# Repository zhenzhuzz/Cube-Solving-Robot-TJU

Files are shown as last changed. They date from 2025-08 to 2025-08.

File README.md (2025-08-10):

# Cube-Solving-Robot-TJU

## 项目概述
`Cube-Solving-Robot-TJU` 是一个自动化魔方机器人，能够通过颜色识别和魔方还原算法，快速高效地还原打乱的魔方。该项目结合了图像识别、计算机算法、机械控制系统与硬件设计，目标是在比赛中完成魔方的自动还原，提升机器人的速度与精度。

该项目的魔方机器人采用了双臂和二指设计，符合比赛的具体要求，旨在通过精确的颜色识别、快速高效的魔方解法和精密的机械结构来实现比人类更快速和准确的魔方还原。

## Demo
Cube-Solving-Robot-TJU Demo

## 图片展示

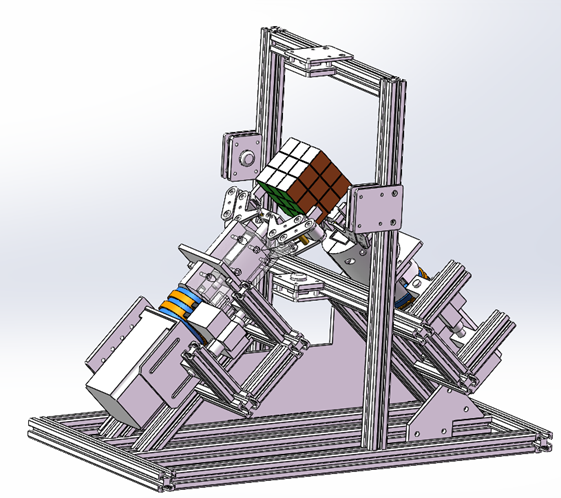
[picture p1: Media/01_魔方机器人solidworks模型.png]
魔方机器人solidworks模型
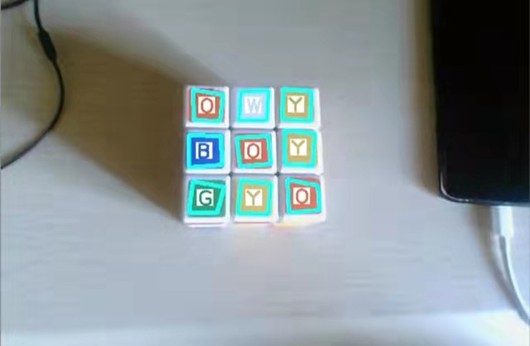
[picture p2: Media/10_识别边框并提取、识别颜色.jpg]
识别边框并提取、识别颜色
|  <br> *SolidWorks模型* |  <br> *识别边框并提取、识别颜色* |
| --- | --- |
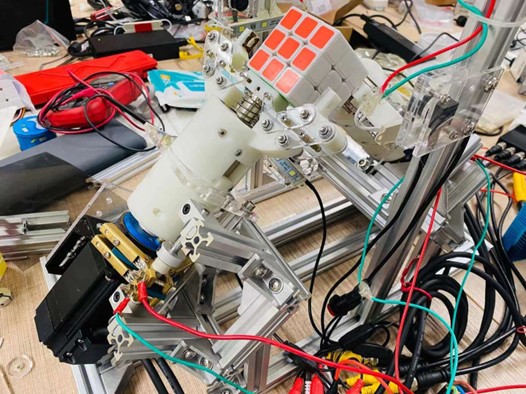
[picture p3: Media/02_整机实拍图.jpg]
整机实拍图
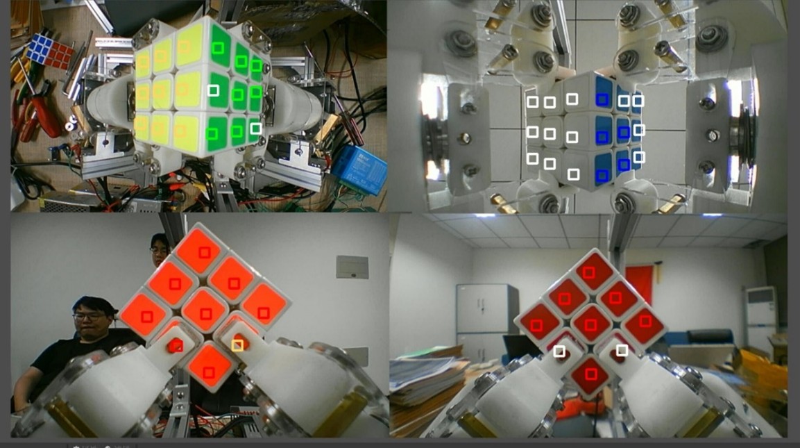
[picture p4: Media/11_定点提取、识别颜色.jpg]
定点提取、识别颜色
|  <br> *整机实拍图* |  <br> *定点提取、识别颜色* |

## 主要不足与改进建议
1. 建议放弃电磁铁驱动——虽响应快，但调试复杂、夹持力不足易掉落、电感大断电后反向电流易损坏继电器或 MOSFET，且长时间通电易烧毁线圈；相比之下，气缸虽速度慢，但力大且更可靠。  
2. 主体框架过度依赖角码螺栓和亚克力板，悬臂结构多、刚度不足，在手爪碰撞或夹持力作用下易产生位移。建议改用三角撑加固，并结合全槽铝型材与焊接或铆接方式，确保一次定位后不再松动。  
3. 赛前大幅结构调整风险高——比赛当日的微调易破坏此前的标定（如颜色识别的定点坐标）。应在光学与算法调试前，先完成并锁定机械结构。  
4. 手爪螺栓连接过多，运转振动中易松动。建议优化手爪结构或采用成品气动爪，减少维护工作量。  

## 比赛要求
根据比赛规则，本项目的魔方机器人满足以下要求：
- **双臂设计**：机器人使用双臂系统来操作魔方。
- **手指形式**：手指设计为二指形式，符合比赛的限制。
- **手腕转动与摆动**：手腕部分允许转动和摆动，以便完成魔方的操作。
- **固定手臂**：手臂本身是固定的，不会移动。
- **外形尺寸限制**：机器人的外廓尺寸不超过 480mm * 480mm * 480mm。
- **重量限制**：总重量不超过 20kg。
- **摄像头**：摄像头数量不限，机器人可自行增设光源。
- **魔方**：竞赛使用标准三阶魔方，决赛用魔方由组委会统一提供。

## 项目功能
- **颜色识别**：通过多个摄像头实时捕捉魔方的颜色块信息，并通过卷积神经网络（CNN）和机器学习算法实现高精度的颜色分类。
- **魔方还原算法**：使用二阶段算法（Kociemba's Algorithm）来解魔方，保证了在短时间内得到一个不超过20步的最优解。
- **控制系统**：使用Arduino控制系统，通过PWM调速步进电机和电磁铁控制机械臂与手爪精确执行魔方还原动作。

## 核心部件
### 1. 颜色识别系统
- **摄像头**：使用四个720P广角摄像头对魔方进行实时拍摄，每个摄像头负责不同角度的色块采集。
- **图像处理**：为了确保颜色识别的准确性，图像会经过腐蚀操作，以去除反光和噪点。使用基于CNN的深度学习模型进行颜色分类，确保高精度的识别，尤其在不同光照条件下。

### 2. 魔方还原算法
- **Kociemba算法**：该算法通过将魔方还原过程分为两个阶段，首先寻找一个阶段一的解，再通过阶段二的搜索得到完整的解。Kociemba的算法可以在几毫秒内生成一个最优解，平均不超过20步。
- **错误校验机制**：为了防止颜色识别误差导致的失败，系统会对魔方状态进行校验，确保颜色数据的准确性。若识别结果不符合标准，系统会自动重新识别。

### 3. 控制系统
- **Arduino控制板**：作为机器人“大脑”，接收并解析从计算机传输的还原步骤指令，控制步进电机、继电器、电磁铁等执行部件。
- **步进电机和电磁铁**：通过步进电机精确控制机械臂的旋转角度，电磁铁则负责操控机械手爪的开合。电磁铁的反应时间控制在15ms以内，确保动作迅速。

### 4. 执行系统
- **机械臂**：机械臂由3D打印技术制作，采用推拉式电磁铁驱动，提供高效、稳定的夹取动作。
- **手爪**：手爪采用电磁铁控制，具有极高的精度和反应速度，能够迅速夹取或松开魔方。

## 项目结构
```bash
Cube-Solving-Robot-TJU/
├── docs/          # 项目文档
│   ├── overview.md         # 系统概述
│   ├── hardware.md         # 硬件结构
│   ├── algorithm.md        # 算法设计
│   └── results.md          # 测试与结果
├── src/           # 代码源文件
│   ├── color_recognition/  # 颜色识别相关算法
│   │   ├── color_detection.py
│   │   └── cnn_model.py    # CNN模型代码
│   ├── cube_solver/        # 魔方还原算法
│   │   ├── kociemba.py     # Kociemba算法实现
│   │   └── solver.py       # 其他还原算法
│   ├── control_system/     # 控制系统及执行系统
│   │   ├── arduino_control.py
│   │   ├── motor_control.py
│   │   └── electromagnet.py # 电磁铁控制
│   └── utils/              # 工具函数
│       └── image_processing.py
├── hardware/      # 硬件设计文件
│   ├── pcb_design/           # PCB设计文件
│   ├── schematics/           # 电路原理图文件
│   └── 3d_models/            # 3D打印模型
├── data/          # 数据文件，包括训练数据、日志等
│   ├── training_data/        # CNN训练数据
│   └── logs/                 # 运行日志
├── README.md      # 项目说明文件
└── LICENSE        # 项目许可证
```

安装与运行
-----

1. **安装依赖**：  
    该项目使用Python编写，依赖以下库：
    
    ```bash
    pip install -r requirements.txt
    ```
    
2. **运行颜色识别**：  
    运行颜色识别模块来进行魔方色块的提取与分类：
    
    ```bash
    python src/color_recognition/color_detection.py
    ```
    
3. **解魔方**：  
    使用Kociemba算法解决魔方，计算最优解：
    
    ```bash
    python src/cube_solver/solver.py
    ```
    
4. **控制执行系统**：  
    启动Arduino控制系统，并通过串口接收指令执行动作：
    
    ```bash
    python src/control_system/arduino_control.py
    ```

数据
--

### 颜色识别数据

为了训练CNN模型，我们使用了多个光照条件下的魔方色块图像数据集。该数据集经过标注，包含不同角度、不同光照条件下的RGB数据。数据集主要用于训练颜色分类模型，提高在真实环境中的识别精度。

### 算法结果

使用Kociemba算法解魔方时，项目会输出每一步的旋转指令，控制机械臂和电磁铁执行相关动作。经过测试，魔方还原时间平均为20秒，且还原正确率超过90%。

项目优势
----

1. **高精度颜色识别**：采用CNN和集成学习算法，确保了在不同光照环境下的高识别准确率。
    
2. **快速魔方解法**：通过Kociemba算法，能够在极短的时间内求解魔方的最优解，减少了机器人的运动时间。
    
3. **稳定高效的控制系统**：Arduino控制系统配合步进电机和电磁铁驱动，确保了机械臂和手爪的稳定性和精确性。
    
4. **可扩展性强**：模块化设计，使得系统易于维护和扩展，可以根据需要进行硬件或算法的升级。

许可证
---

本项目采用 MIT License 许可协议。

致谢
--

感谢所有开源工具和库对本项目的支持，尤其是`OpenCV`、`TensorFlow`、`Kociemba`库以及`Arduino`社区的贡献。

```

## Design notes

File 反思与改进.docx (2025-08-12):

1、建议不要使用电磁铁。电磁铁虽然理论上比气缸响应速度快，但调试起来非常麻烦。这次比赛我们魔方2组采用了电磁铁，主要有三个缺点：

一是力不够，能买到的电磁铁最大的保持力为65N，但还是会在魔方转动的过程中因为夹持力不够而掉落，远不如气缸的力大。

二是电磁铁内部的电感很大，因此在断电时仍会有很大的电流存在，电流从电磁铁流出，从继电器的输出端流入，有可能会击穿继电器。在整个调试过程中，我们烧坏了2个继电器（虽然继电器是机械结构控制通断，但还是有可能击穿），以及很多个MOS管（继电器都能击穿，更不用说MOS管了）。

三是不能长时间通电，使得调试过程很麻烦。电磁铁主体是线圈，长时间（不超过30s）通电会烧坏，因此调试时得时刻记着给电磁铁断电，比较麻烦。

再结合比赛时其他高校的情况来看，绝大多数都是使用气缸，因为更稳定而且容易控制。由于我们学校的魔方机器人经验还不足，因此应该先把重心放在制作出能稳定还原魔方的机器上，不用刻意追求速度。

2、制作的主体框架不稳定。我们2组主体框架用的是铝型材和亚克力板，连接用的是角码和螺栓，还有多处是悬臂梁，结构不稳定。因此在手爪故障，发生碰撞时会使支撑结构发生位移，从而严重影响手爪的对中性。因此以后设计支座应该多利用三角形结构，并且多开槽开销孔，将底座完全固定，这样在调整好对中后，就不会再受手爪碰撞的影响。

3、切忌赛前大调结构。我们组的机器人在比赛前一晚还能正常运行，但在比赛当天早上因为手爪夹不紧，所以不断调整手臂的位置，使得原本固定好的颜色识别的点发生了移动，因此在比赛时没能识别魔方的颜色，这种行为应该极力避免。因为我们颜色识别采用的是定点识别，因此调试好设备后，手爪的位置就不能动了，这样才能保证打的点都落在魔方正确的色块上。

4、机械结构一定要尽早搭出来，后期调灯光和颜色识别还需要一定时间。机械结构一定要以稳为主，支座一定要固定好，这样在后期调试的时候才能确定下环境。魔方机器人最重要的就是保证环境不变，因此整个结构要有很好的抵抗外界变化的性能，无论是魔方滑落发生碰撞，还是环境灯光发生变化，都不能影响手臂结构和魔方的识别。

5、我们组的手爪采用了太多螺栓连接，在转动时是螺栓在转动，因此调试几次后手爪上的螺栓就会松了，使得调试过程非常麻烦，需要反复拧紧，建议下次改良一下手爪结构，或者直接买气动手爪来使用。

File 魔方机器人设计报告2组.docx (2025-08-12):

指导教师：宋晓威 于树强 参赛队员：朱 镇 段金宇 李姝影

魔方机器人设计报告

天津大学代表队

# 一、系统概述

## 1.1 项目背景

中国高校智能机器人创意大赛是一项有广泛影响的全国性的学科竞赛。2017年首届中国高校智能机器人创意大赛由中国高等教育学会、教育部工程图学课程教学指导委员会、中国高校智能机器人创意大赛组委会共同主办，浙江大学机器人研究院、中国高等教育学会工程教育专业委员会承办，决赛由浙江省余姚市人民政府承办。之后该大赛每年举办一次，至今已经连续举办3届，大赛以“更好、更快、更强”为主题，既培养学生提问题的能力，也培养学生解决问题的能力，高校参与该竞赛的积极高、参与面广，本竞赛已列入中国高等教育学会发布的《2020年全国普通高校学科竞赛排行榜》。

为进一步推进高校学生创新意识和创造能力培养，激励广大学生踊跃参加课外科技实践，有效推动新工科人才培养，经中国高校智能机器人创意大赛组委会研究，决定启动第四届中国高校智能机器人创意大赛工作。

第四届中国高校智能机器人创意大赛设三个主题和一个邀请赛，鼓励学生根据自己的专业特长和兴趣爱好选择其一参赛。其中，主题二（创意竞技）为“魔方机器人——挑战更快”：参照人类魔方竞速规则，设计制作魔方机器人，综合运用机械、电子、信息和自然科学知识，实现比人“计算”更快、“翻动”更加灵活迅速的目标。

## 1.2 需求分析

在研读历届魔方机器人决赛程序和裁判规则的基础上，我们发现，比赛对还原魔方的速度、准确性，机械结构的稳定性均提出了一定的要求，经过分析，我们认为魔方机器人至少需要具备以下功能：

## 1.2.1颜色识别

魔方机器人需要在一定的光照条件下（可加人工光源），识别魔方各色块的颜色，从而获得RGB信息。颜色识别需要对每个方块的颜色精确把握。近年来ｏｐｅｎｃｖ的发展使得此项成为现实。

### 1.2.2 魔方还原算法

获取魔方各面的颜色数据（包括颜色信息和位置／顺序信息）后，魔方机器人通过算法将数据转化为特定形式作为输入量求解还原步骤，还需要一个辅助程序优化理论还原步骤，进一步简化得到实际还原步骤，然后输出可执行步骤给执行系统，从而还原魔方，这要求还原魔方算法的简洁高效；

## 1.2.3控制算法及电路系统

得到还原魔方算法输出数据后，需要一套控制算法及相应配套的电路系统将还原步骤传递给执行系统，而控制系统不宜复杂，应保证稳定高效，能快速响应。

## 1.2.4执行机构

执行机构应满足精度要求，保证手爪对中性以及和魔方的匹配程度，确保在还原魔方的过程中，将误差控制在容错范围内，尽量避免误差积累带来的影响。在控制系统的控制下，执行机构需要稳定且准确地完成给定动作，为防止魔方在还原过程中受力移位、脱落，执行系统及主要机械结构对相关构型及材料具有一定的受拉、受压等强度要求。

## 1.3 项目预期

在参考往届众多优秀作品的基础上，我们将针对性地对视觉识别算法及机械结构进行大幅改进，预计可使颜色识别更加准确快速，机械爪结构更加稳定，制作及装配精度更高，识别准确率预期在95%以上，还原魔方速度预计在20s内，总时长预计在25s内，还原正确率预计在90%以上。

# 二、作品简介

## 2.1 总体构成

本组的魔方机器人总体使用了Arduino 1块，电磁铁2个，PCB板1块，MOS管2个，220V/AC-24V/DC开关电源1个，220V/AC-12V/DC开关电源1个，720P摄像头4个，采集卡1块。电机及支架和驱动器2组，电滑环及碳刷2组，6mm光轴2根，锁紧环4个，光轴支承座4个，3D打印件手爪2个，LED小灯4条、铝型材、轴承、螺母、连接件、角码、导线等若干。

## 2.2 机械结构

二轴魔方机器人结构示意图如图2.1所示，图中，魔方机器人的外部框架均为铝型材。

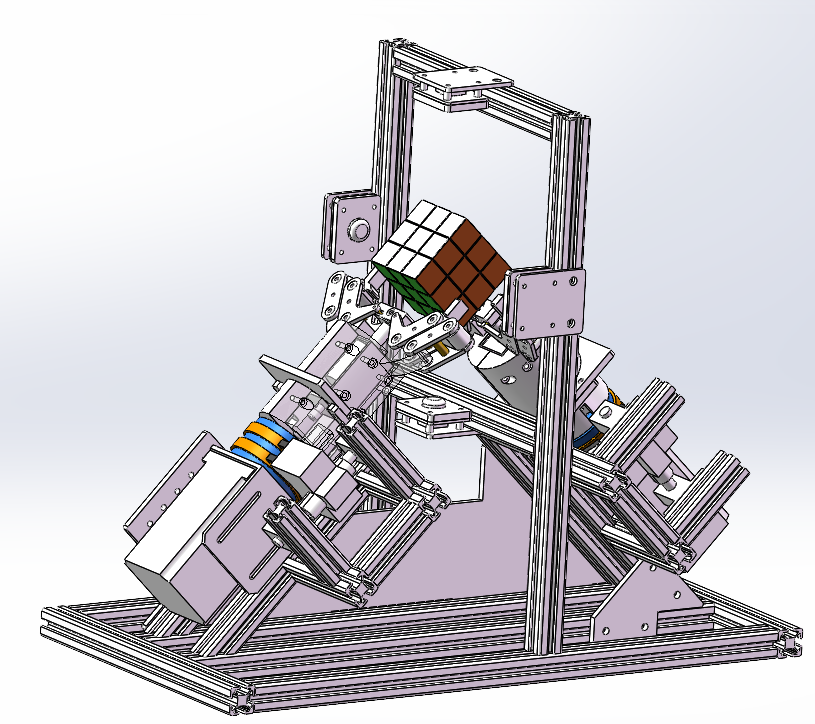
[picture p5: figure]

图2.1 魔方机器人solidworks模型

魔方机器人以中间门形框架所在的平面为基准面左右对称，两侧的三角支架上装有闭环步进电机，通过联轴器与机械臂相连。联轴器外固定有电滑环，配合电刷，解决电磁铁的绕线问题。手指通过手指连接件与机械臂相连，其夹放动作通过机械臂内部的推拉式电磁铁进行控制。闭环步进电机、机械臂、滑环的回转轴都位于同一轴线上，且与另一侧轴线呈90°夹角，魔方也位于该角处。机器人的图像采集通过固定在门型框架上的四个摄像头实现。

在功能分工上，机器人整体按照可分为动力系统、控制系统和执行系统。两臂的两个步进电机由驱动板供电，控制手臂的旋转；通过电磁铁控制手爪的开合。使用Arduino通过串口接收计算机发来的还原步骤，经过处理加工计算后得到魔方还原的指令，将计算机的每个指令翻译为一组信号输出。通过Arduino，实现对电机驱动板和电磁铁的控制，利用PCB简化连线，利用MOS管代替继电器。气泵控制手爪开合，电机驱动板驱动电机控制手臂旋转，两者配合完成一次完整的拧转动作。

## 2.3 算法设计

在算法设计上，本组魔方机器人的主算法由图像识别位置校准程序、图像识别程序、图像分割显示程序、图像信息转换程序、还原算法、坐标转换程序和控制程序七个子程序组成。

图2.2 程序框图

# 三、硬件结构

## 3.1 输入元件

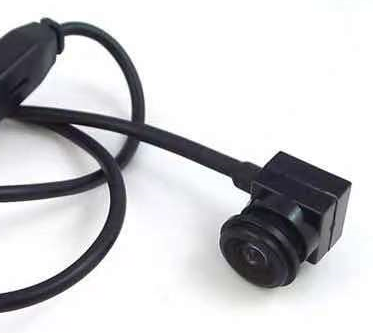
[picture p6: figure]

图3.1 摄像头实物图

本魔方机器人使用4个平头广角720P摄像头作为色彩信息输入元件。

## 3.2 控制系统

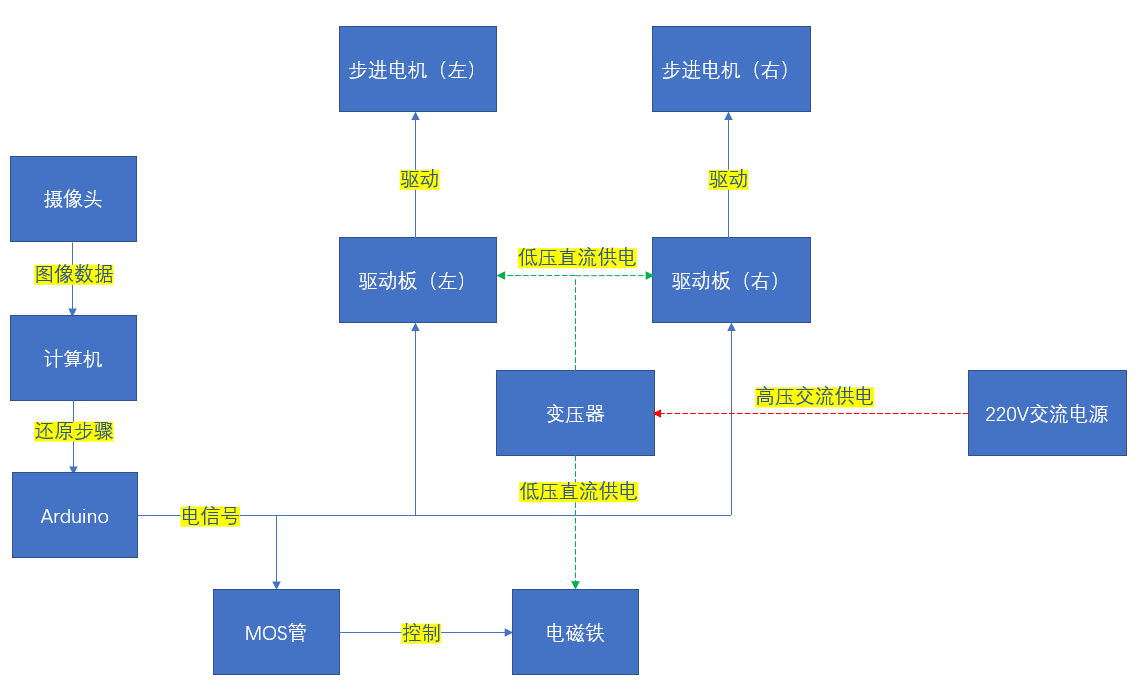
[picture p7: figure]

图3.2 控制系统框图

采用计算机作为本魔方机器人的“大脑”，处理摄像头输入的数据，并求解还原魔方的步骤，输出给Arduino；使用Arduino作为机器人的“脊髓”，通过串口接收计算机发来的还原步骤，经过处理加工计算后得到魔方还原的指令，并将计算机的每个指令翻译为一组信号输出，实现对电机驱动板的控制，控制手臂旋转，通过MOS管控制电磁铁，以此控制手爪开合，两者配合完成一次完整的拧转动作。

MOS管采用A0D4184型号，击穿电压电流分别为40V、50A，自带光耦隔离，控制信号和被控设备电源隔离，大大提高刚干扰，可兼容Arduino控制板，高电平启动，低电平停止，PWM调速。

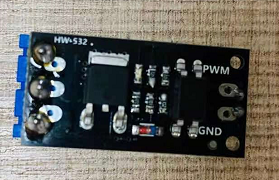
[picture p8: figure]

图3.3 MOS管实物图

本组自行绘制一版PCB，提前将铜线布好，将MOS管，Arduino，24V，地线以及电机使能、步进、旋转方向集成在板子上，方便接线，机器的封装性更好

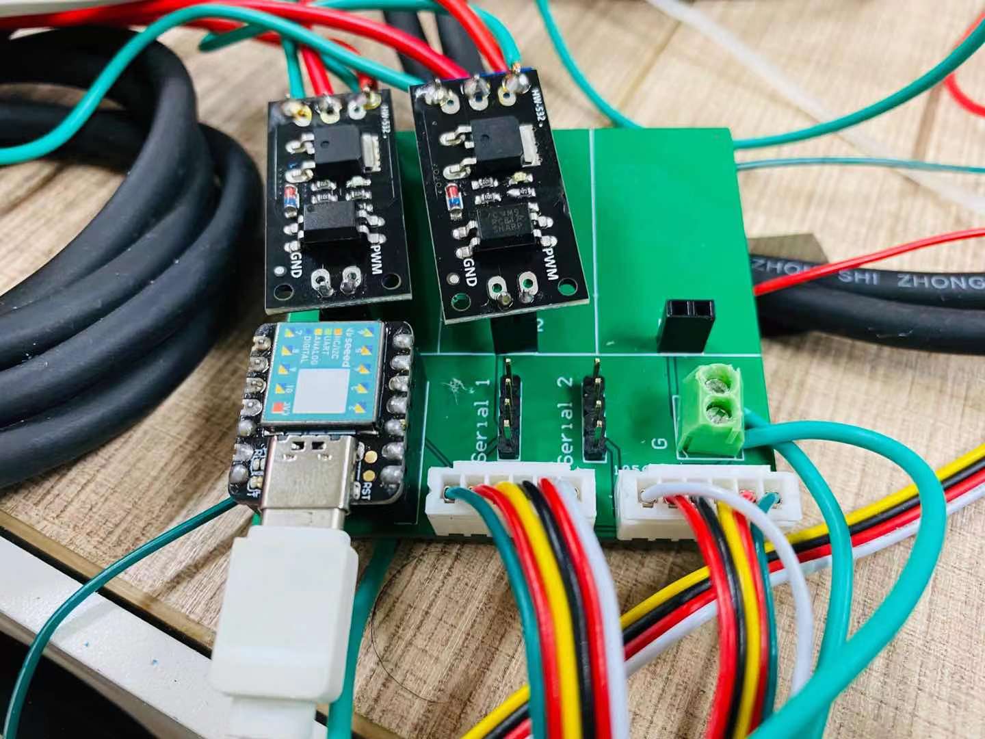
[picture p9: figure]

图3.4 MOS管和Arduino集成在PCB上的实物图

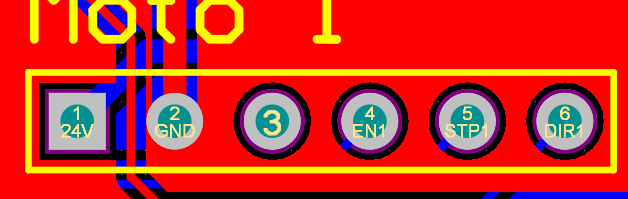
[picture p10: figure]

图3.5 PCB端子绘制图

## 3.3 执行系统

## 3.3.1 电磁铁

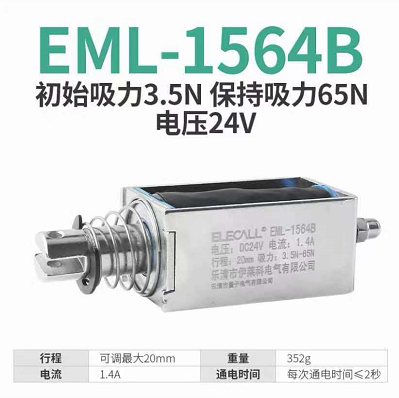
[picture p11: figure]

图3.6 电磁铁实物图

本组采用推拉式电磁铁，型号为伊莱科的EML-1564B，工作电压24V，工作电流2A，初始吸力3.5N，保持吸力65N，重量352g，最大可调行程20mm。通过电磁铁推动手爪结构，带动手指张开闭合，从而实现抓紧和松开两种状态。并且电磁铁响应迅速，与气缸相比执行速度更快，还原魔方的速度更快。

## 3.3.2 机械臂

机械臂内部结构如图3.7所示：

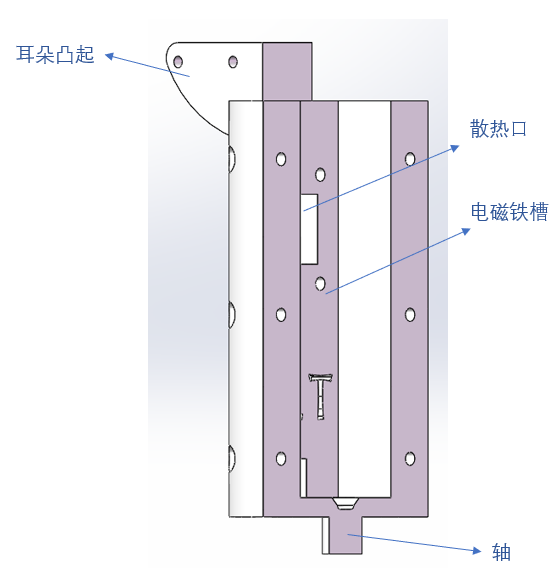
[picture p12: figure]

图3.7 机械臂内部结构

机械臂采用3D打印技术制作，内部有电磁铁槽，用来安装推拉式电磁铁。下端的圆柱状凸起为机械臂的轴，利用联轴器与电机轴固定。手指连接件与机械臂上端的耳状凸起相连，牵引手指的夹放动作。在一边的机械臂的轴上还设计有一个平键，用以保证机械臂和联轴器的连接，如图3.8所示。

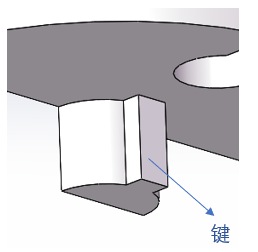
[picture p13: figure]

图3.8 轴上的键

## 3.3.3 机械手爪

本魔方机器人每一手臂末端有两个手指，均由3D打印材料制作，通过I型手指连接件和L型手指连接件分别与机械臂的耳状凸起及手掌连接。手掌与电磁铁的铁芯连接。机械手爪的结构图如图3.9所示：

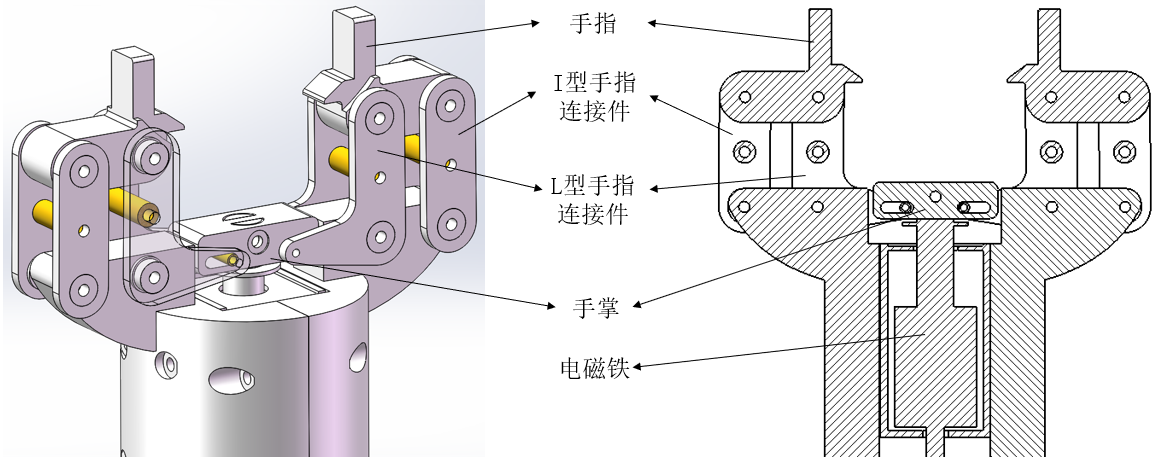
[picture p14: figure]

图3.9机械手爪结构示意图

当电磁铁通过电流时铁芯收缩，电流断开时通过弹簧弹出铁芯，从而带动手掌上下运动，推动L型手指连接件、I型手指连接件运动，实现手指夹放动作。

## 3.3.4 步进电机

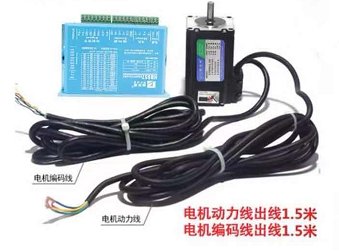
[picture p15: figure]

图3.10 步进电机实物图

电机采用57闭环步进电机，型号为57HSZ2N，输出力矩2.2N·m，机身长度99mm，轴径8mm，出轴方式为单出轴，电流为4A，转速1000rpm以上扭矩下降，最高2000rpm。

电机轴与联轴器相连，联轴器又与机械臂想连，从而带动机械臂转动。

## 3.3.5 电滑环

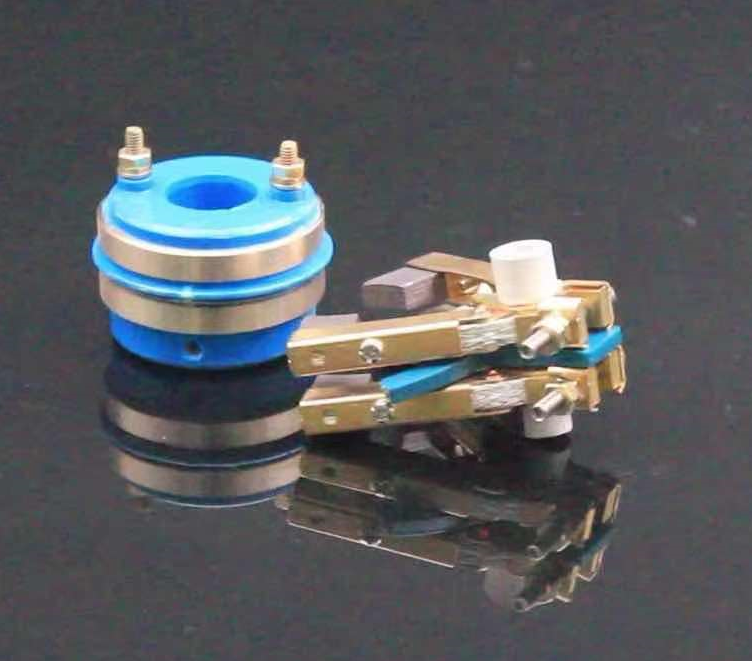
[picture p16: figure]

图3.11 电滑环和电刷实物图

电磁铁的导线通过电滑环和电刷来连接电源，使得电磁铁旋转时，导线不会缠绕起来。电滑环选用人字形刷架总成二组SR20*50*34-2。

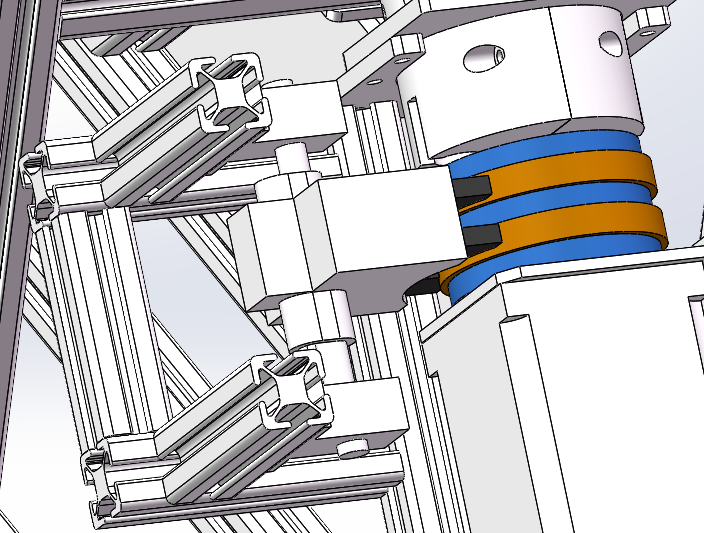
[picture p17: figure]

图3.12 电滑环和电刷的安装位置

## 3.4 动力系统

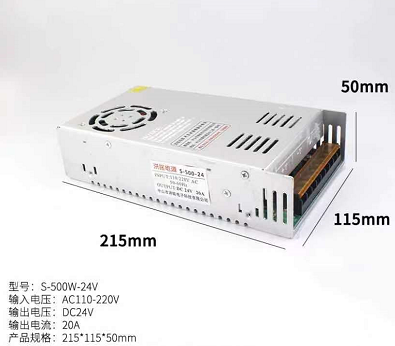
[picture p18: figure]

图3.11 变压器实物图

电源方面选择220V家用交流电转24V直流电，所用变压器为S-500W-24V变压器，长215mm，宽115mm，高50mm，输入电压范围为110V~220V/AC，输出电压为24V/DC，最大输出电流为20A，最大功率500W。

# 四、控制算法及软件实现

软件算法是魔方机器人核心，其大致可分为三个部分，颜色识别、解魔方、控制机构运动，其中颜色识别和解魔方我们使用Python语言使其运行在个人电脑上，控制机构部分我们使用Arduino来控制电机的转动，继电器的开闭等动作，以下将对各部分进行详述。

## 4.1 颜色识别

对于颜色识别的算法，我们首先需要进行对魔方上各个色块的颜色进行采集。我们想到的有两种方法：第一个是对魔方进行边框的识别，通过算法筛选出其9个色块，这样就可以知道我们所需要颜色的位置。这种方法虽然非常方便，但在实际的运用中效果并不是特别好。由于机械臂上会有各种的机构挡住魔方一定部分，使边缘识别的成功了大幅减小，非常不稳定，而在比赛中我们需要的是其能够稳定得运行。所以我们将这种方法运用到后面其他的地方。

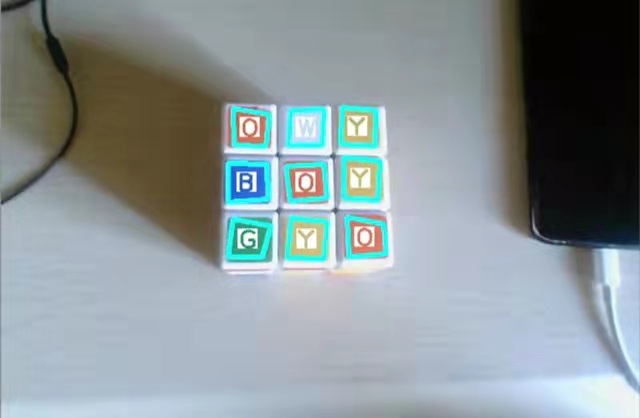
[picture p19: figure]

图4.1 识别边框并提取、识别颜色

由于魔方在机械臂上的位置是固定的，所以便可以取第二种方法，对摄像头图像的进行定点识别。这种方法的缺点是在前期进行调试时非常麻烦，需要设各点坐标，同时需要魔方和摄像头的位置不能有一丝轻微的移动，对于魔方放的位置也提出了很大的要求，但在经过前期调试后这种方法可以非常稳定运行，所以我们使用了第二种定点识别的方法。

### 4.1.1图象腐蚀

但是在取得我们想要的色块之后，由于反光或者是摄像机的噪点，使得用于识别的数据十分杂乱，于是我们就使用了图形学中的“图象腐蚀”操作对数据集以及进入识别的图象进行了处理。

如下图就是图象腐蚀算法处理的结果，可以看到结果很好。

图4.2 未经腐蚀的图象

图4.3 腐蚀结束的图象

如上图所示，经过腐蚀后的图象以及完全消去了反光带来的影响。符合我们对数据的要求。

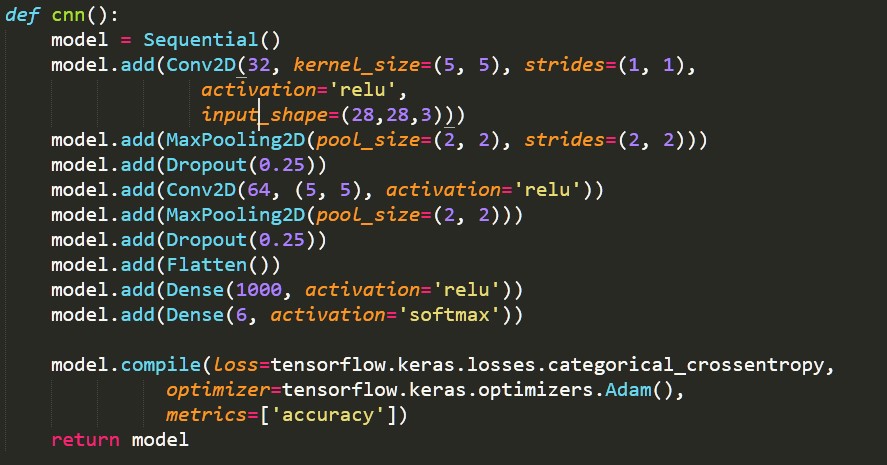
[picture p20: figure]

在取得我们所需要的颜色值后我们就需要通过算法来判断该颜色值是什么，首先我们尝试了对RGB数值设置阈值来判断，但这种方法需要人工来调阈值非常麻烦，同时其准确率非常低，不同环境下识别颜色的值相差非常大。所以我们又采用卷积神经网络CNN来进行颜色的识别，只需要采用第一种识别边框的方法通过摄像头采集还原好的魔方的六个面，来非常方便得获取颜色值，再来训练模型，在这种方法下训练的模型在测试训练集时可以达到基本100%的准确度。

图4.4 CNN的结构

但其在实际运用的时候却在上下摄像头的识别有非常大的失误，由于上下识别需要对两个对角面进行识别。所以我们对其训练集进行了补充，添加了许多不同光照条件下的颜色数据，这种方法后他的准确度大幅提升。但是为了以防万一，我们同时采用了集成学习的机器学习方法训练了另一套识别模式。如图就是我们采用的集成学习的结构。

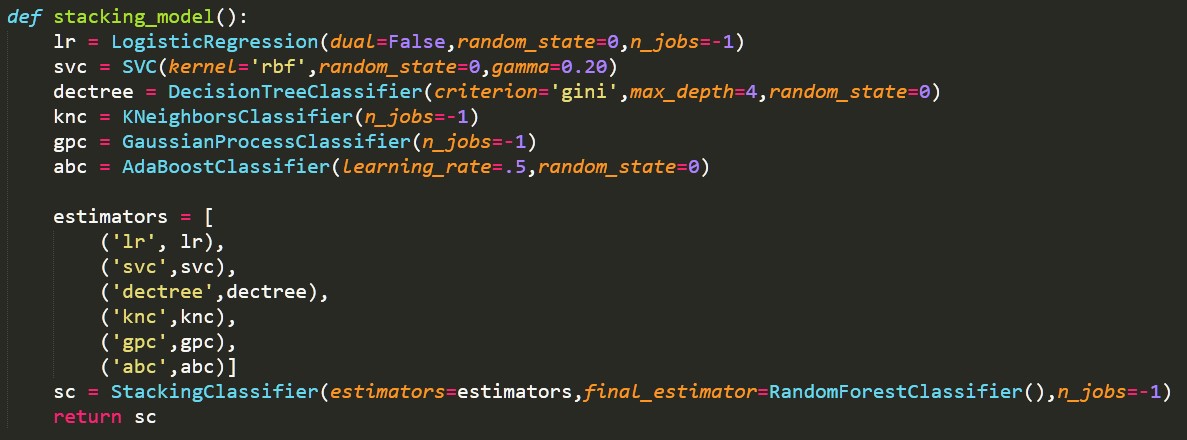
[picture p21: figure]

图4.5　集成学习模型

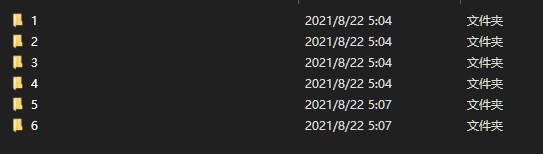
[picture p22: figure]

图4.6 通过机器学习所建立数据的数据库

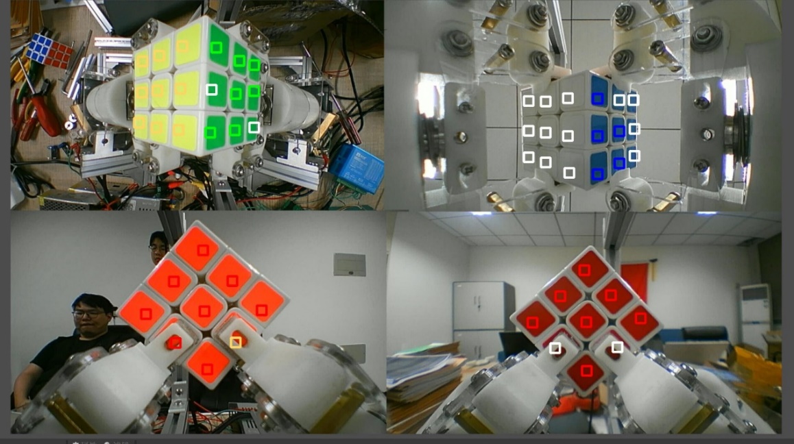
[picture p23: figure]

综上所述，通过首先通过识别边框的方法来获取非常方便快速得获取不同光照下的颜色的RGB值，通过这些大量的数据来进行模型的训练，再通过定点识别的方法来获取实际运行过程中魔方的颜色值，通过调用模型来进行颜色的判断。

图4.7 定点提取、识别颜色

## 4.2 解魔方

解魔方我们采用了当前最主流的计算机解魔方算法，二阶段算法（Two phase algorithm，又称Kociemba's algorithm），在当前计算机上，对于一个充分打乱的魔方，该算法平均可以在几毫秒的时间内得到一个不超过20步的解法。魔方可能的状态数实在太多了，达到4.3*10^19，这是一个很大数量级，而二阶段算法顾名思义，就是把还原的过程分成了两个阶段。首先进行阶段一的搜索，得到了阶段一的最优解。接着通过阶段二的搜索，得到了阶段二解法，从而产生了一个步的完整解法。通过不断搜索解法再进行比较，获得其最快解。由于这个算法过于高深，所以我解魔方为调用Kociemba库来完成。虽然我们已经极力提高颜色的准确率了但是若光照改变，其所识别的颜色还是会有几率错误，某个色块的颜色会在两种颜色中跳动，而将错误的颜色信息输入Kociemba库，整个程序将会报错，从而导致运行失败，所以我们设计了检验程序，将颜色分别标为1，2，3，4，5，6，将所有面的颜色相加，若其不等于21*9，那么便说明识别中有错误，需要重新进行识别。然后这一步遇到的最大的困难是对四个摄像头依次识别数据的处理，使其成为其库的标准输入，即每个面都有一个字符表示，U为上表面，D为下表面，L为左表面，R为右表面，F为前表面，B为后表面，解完的魔方每个面都是同一个颜色，所以UDLRFB可以代表每个面的颜色。假定我们让上表面U为白色，下表面D为黄色，左表面L为红色，右表面R为橙色，前表面F为蓝色，后B表面为绿色。当魔方打乱后，则下图表示的每个面的单元格颜色就可能是之前任何面的某一个颜色，这样便可以让魔方可任意摆放在手臂上。我们按照如下顺序将单元格颜色变成字符串：`U1`, `U2`, `U3`, `U4`, `U5`, `U6`, `U7`, `U8`, `U9`, `R1`, `R2`, `R3`, `R4`, `R5`, `R6`, `R7`, `R8`, `R9`, `F1`, `F2`, `F3`, `F4`, `F5`, `F6`, `F7`, `F8`, `F9`, `D1`, `D2`, `D3`, `D4`, `D5`, `D6`, `D7`, `D8`, `D9`, `L1`, `L2`, `L3`, `L4`, `L5`, `L6`, `L7`, `L8`, `L9`, `B1`, `B2`, `B3`, `B4`, `B5`, `B6`, `B7`, `B8`, `B9`。所以当我们输入字符串"UBL..."，表示U1为白色，U2为绿色，U3为红色，以此类推，即可定义所有面的单元格标志字符串。

以下便是各字符所在的位置：

|************|

|U1*U2*U3|

|************|

|U4*U5*U6|

|************|

|U7*U8*U9|

|************|

|***********|***********|***********|***********|

|L1*L2*L3|F1*F2*F3|R1*R2*R3|B1*B2*B3|

|***********|***********|***********|***********|

|L4*L5*L6|F4*F5*F6|R4*R5*R6|B4*B5*B6|

|***********|***********|***********|***********|

|L7*L8*L9|F7*F8*F9|R7*R8*R9|B7*B8*B9|

|***********|***********|***********|***********|

|************|

|D1*D2*D3|

|************|

|D4*D5*D6|

|************|

|D7*D8*D9|

|************|

再将其输出处理为我们需要数据。解魔方步骤字符串包含空格字符，含义如下：

- 单个字符表示所代表的面顺时针旋转90度。
- 单个字符带一撇，表示代表的面逆时针旋转90度。
- 单个字符带2，表示代表的面旋转180度。

比如R U R’ U R U2 R’ U, 表示右表面顺时针旋转90度，下表面顺时针旋转90度，右表面逆时针旋转90度，下表面顺时针旋转90度，右表面顺时针旋转90度，下表面旋转180度，右表面逆时针旋转90度，下表面顺时针旋转90度。Kociemba库输出的步骤只是六个面的转动，而由于我们的魔方是双臂四指来完成步骤，所以我们需要进行坐标系的转换，例如Kociemba库解出的算法为将U面进行顺时针旋转90度，而我们的机械结构需要现将魔方整个进行翻转，来让处于上面的U面转至下面，从而使手臂可以拧到这个面，而在这个过程中整个魔方的坐标系就会进行旋转，Kociemba库解出的后面的步骤就要进行改变。这样输出的步骤便是我们希望手臂所能进行的运动。我们便可将其传入Arduino。

## 4.3 魔方控制

最后便是电脑与Arduino之间的通信与Arduino控制机械的运动，将解出电脑来的通过调用serial库来通过串口通信来将步骤的字符串传给Arduino，Arduino每次读取两个字符那便是单个步骤，同时剩余的步骤将存在于数据缓存区，Arduino同时也会通过串口来将步骤完成的信息进行反馈，以此来达到计时的目的。在Arduino收到步骤信息后它便要输出不同PWM信号来控制电机的转速，逻辑信号控制电机的正反转，逻辑信号控制继电器的开关以此来控制电磁的开关从控制手臂的张合。对于两个逻辑型号非常简单，只需输出高低电平，需要注意的是继电器的连接端的选择使手臂在低电平的信号下为闭合状态，在输入高电平是张开状态。

而PWM信号则会复杂许多。步进电机（也称脉冲电机），将电脉冲转换为相应的角位移或线位移的电磁机械装置，具有快速启动，停能力，在电机的负荷不超过它能提供的动态转矩时，可以通过输入脉冲来控制它在一瞬间的启动或者停止。在非超载的情况下，步距角和转速只和输入的脉冲频率有关，和环境温度，气压，振动无关，也不受电网电压的波动和负载变化的影响，因此，控制较为精准，即给电机一个脉冲信号，电机则转过一个步距角。信号开始运行后，步进电机将从0度旋转目标度数，每次一个分度。而转速则为PWM信号的频率决定的，一个脉冲信号，便会转一个分度。在调试完后我们需要使电机转速提升，这就需要我们加快频率，而当频率到超过Arduino上限时我们便要调低分度值，这是便会发现电机由于转速太快会丢步。这就需要我们对电机的启动与停止来设置加速度，即使PWM信号的频率由低到目标值，再由目标值到0。这样电机的转速便会由一开始的慢变快，再由快变慢。从而使其的峰值转速达到非常高而不会丢步，而由于加速时间和减速时间其实非常短，所以总的转速时间会有非常大的提升。从而加快整个机构的速度。

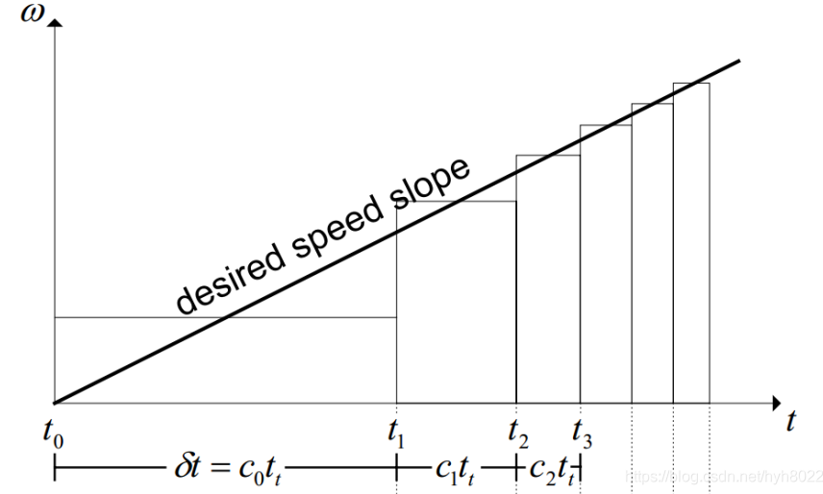
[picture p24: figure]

图4.8 步进电机加减速的实现

# 五、总结

## 5.1 优势

1、按系统功能分，机器人整体可分为动力系统、控制系统和执行系统。在执行逻辑上，首先4个摄像机得到指令后拍摄图片并发送至计算机。然后计算机处理图像并提取色块信息，通过算法解算出步骤后发送信号至下位机。最后下位机控制电机旋转与电磁阀的开闭，进而完成手腕拧转和手指夹取的基本动作。通过以上三个步骤还原打乱的魔方。

2、机械手爪的驱动控制。本作品的机械手爪夹、放动作的驱动装置为电磁铁，具有反应速度快、成本低、重量轻、体积小的优点。

3、机械手爪的机械结构。为配合电磁铁的驱动特性，本机械手爪结构极具创新特色。其两个手指均采用I型和L型手指连接件与机械手臂和手掌相连，通过电磁铁弹出、收进手掌来控制手指的夹、放动作。该结构性能稳定、反应迅速，在电磁铁的驱动下可高效完成手指的夹、放动作。

4、采用半遮光-多摄像头图像识别策略，提高识别精度，缩短识别时间。通过不完全透明的亚克力板提供较为柔和的光照，保证图像亮度；将包含图像信息的RGB空间数据，实现色调与饱和度、明度的分离，提升颜色识别的简便性和准确性；多摄像头的设置避免采样时手臂需多次旋转的问题，大大缩短图像识别时间识别。

5、使用Python开源算法库Kociemba，解算过程时间短效率高，解算结果步骤简单步数少。使用强大的功能函数kociemba.solve()，能够轻易在ms级的时间得到平均20步（5次测量的数据）包含还原步骤的字符串，再通过Python的字符串处理函数规范化字符串，得到能够被下位机识别的指令序列。

经过多次测试，该魔方机器人能高标准完成机器人大赛给出的任务，效果出色，性能稳定，还原速度快。

## 5.2 可以改进的方面

在调试的过程中，我们还发现了许多可以改进的方面：

1.机械结构材料及其精度。不同的零部件采用不同的材料，有各自的机械精度，在组装时又会有一定的精度差。故魔方机器人整体机械结构的精度对魔方复原的稳定性有一定影响，当转速过快时，会出现魔方滑落甚至甩出的现象。

针对此现象，小组尝试不同的3D打印材料，以提高机械臂和机械手爪的精度；不同机械零件连接时，加强固定力度；在手指内侧粘贴橡胶膜，增大手指与魔方之间的摩擦力。

2.光线强度变化。自然条件下，外界光线会随时间而发生变化。光线强弱影响了摄像头对魔方色块颜色的识别与提取，会使上位机获得错误信息。

针对此现象，小组采用补光设备，使魔方周围光线尽量保持不变，削弱自然光变化而产生的影响。

3.电磁铁的反应周期。小组采用的电磁铁控制电路已经将电磁铁铁芯收缩的时间控制在15 ms 以内，但铁芯的释放过程仍有较长时间，约为60 ms 。

针对此现象，小组采取给电磁铁增设弹簧的方法，加大铁芯释放所受到的回程力，缩短释放时间。

# 六、实物图

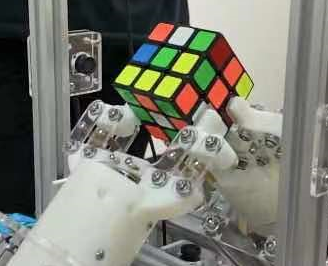
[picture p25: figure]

图6.1 手爪部分实拍图

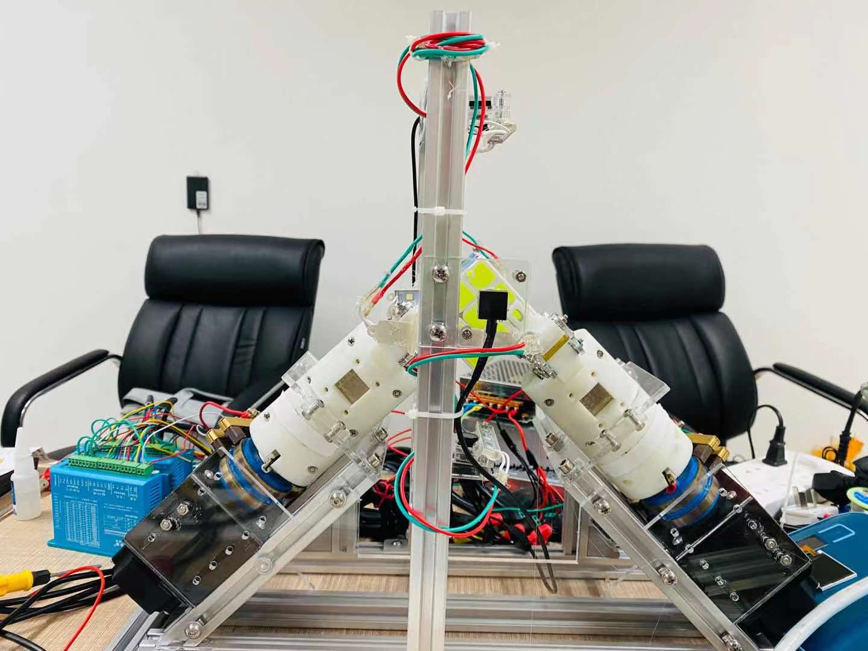
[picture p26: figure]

图6.2总体实拍图

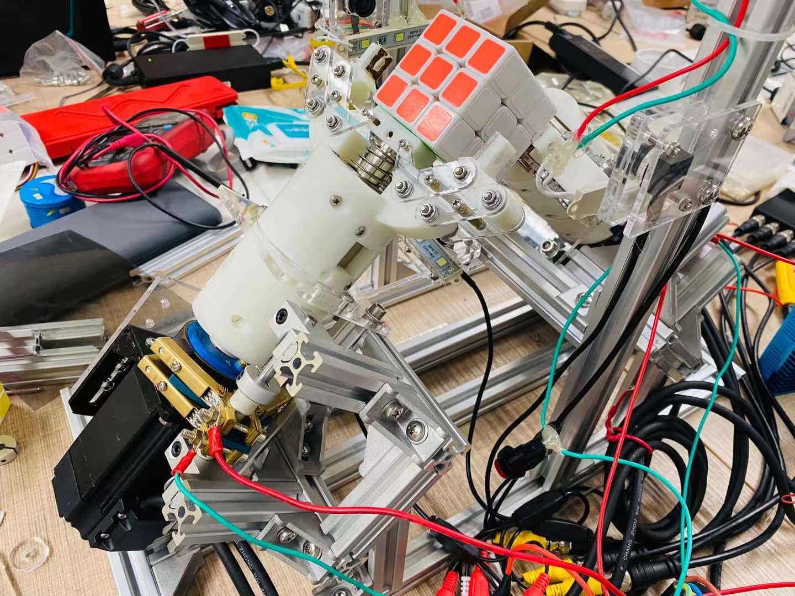
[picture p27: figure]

图6.3 侧视图

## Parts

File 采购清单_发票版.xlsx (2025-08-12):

序号 | 名称 | 规格 | 购买链接 | 单价 | 数量 | 价格（含税） |  | 采购人 | 有无发票 | 备注
1 | STM32F103C8T6开发板最小系统板 | 单片机核心板 | https://detail.tmall.com/item.htm?id=631557979854&spm=a1z09.2.0.0.50192e8df31Cot&_u=92jd7h41f013 | ¥40.98 | 1 | ¥40.98 | ¥40.98 | 朱镇 | 有 | 已焊接
2 | Arduino uno r3入门学习套件 | 标准创客版（含主板） | https://detail.tmall.com/item.htm?id=601125598796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 | ¥103.00 | 1 | ¥103.00 | ¥103.00 | 朱镇 | 有
3 | 45度角铝 | 2020-45度角铝（含紧固件） | https://detail.tmall.com/item.htm?id=576353788076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 | ¥7.56 | 5 | ¥37.80 | ¥243.30 | 朱镇 | 有
4 | 圆柱头内六角螺栓 | M6*16+垫片 | https://detail.tmall.com/item.htm?id=576376737278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 | ¥0.44 | 10 | ¥4.40 |  | 朱镇 | 有
5 | 圆柱头内六角螺栓 | M5*8+垫片 | https://detail.tmall.com/item.htm?id=576376737278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 | ¥0.35 | 20 | ¥7.00 |  | 朱镇 | 有
6 | 圆柱头内六角螺栓 | M5*10+垫片 | https://detail.tmall.com/item.htm?id=576376737278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 | ¥0.35 | 20 | ¥7.00 |  | 朱镇 | 有
7 | 角码 | 2020角码（含紧固件） | https://detail.tmall.com/item.htm?id=576621463575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 | ¥1.90 | 25 | ¥47.50 |  | 朱镇 | 有
 | 滑块螺母 | 欧标20M4 | https://detail.tmall.com/item.htm?id=576220220243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 (https://m.tb.cn/h.4zXMLN4?sm=ecf60e) | ¥0.72 | 10 | ¥7.20 |  | 朱镇 | 有
 | 滑块螺母 | 欧标20M5 | https://detail.tmall.com/item.htm?id=576220220243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 (https://m.tb.cn/h.4zXMLN4?sm=ecf60e) | ¥0.72 | 20 | ¥14.40 |  | 朱镇 | 有
 | 铝型材 |  | https://detail.m.tmall.com/item.htm?id=608414321666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 | ¥118.00 | 1 | ¥118.00 |  | 朱镇 | 有 | 详见铝型材清单
3 | Arduino 下载线 | 1.5m | https://detail.tmall.com/item.htm?id=643970809000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 | ¥7.95 | 1 | ¥7.95 | ¥7.95 | 朱镇 | 有
20 | LM2596S DC-DC直流可调稳压模块 | 5A大功率75W | https://detail.tmall.com/item.htm?id=581544496424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 (https://item.taobao.com/item.htm?id=567829133337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) | ¥15.23 | 1 | ¥15.23 | ¥15.23 | 朱镇 | 有
6 | 304垫圈 | M3*7*0.5 | https://detail.tmall.com/item.htm?id=15730068817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 | ¥1.50 | 1 | ¥1.50 | ¥12.17 | 朱镇 | 有 | 拍1件50颗
7 | 304垫圈 | M4*9*0.8 | https://detail.tmall.com/item.htm?id=15730068817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 | ¥1.50 | 1 | ¥1.50 |  | 朱镇 | 有 | 拍1件50颗
9 | 304十字盘头螺钉 | M3*20 | https://detail.tmall.com/item.htm?id=537903695538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 | ¥3.24 | 1 | ¥3.24 |  | 朱镇 | 有 | 拍1件50颗
8 | 304十字盘头螺钉 | M3*30 | https://detail.tmall.com/item.htm?id=537903695538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 | ¥4.03 | 1 | ¥4.03 |  | 朱镇 | 有 | 拍1件40颗
10 | 双通六角铜柱 | M3*15 | https://detail.tmall.com/item.htm?id=16626695446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 | ¥1.90 | 1 | ¥1.90 |  | 朱镇 | 有 | 拍1件10颗
5 | 继电器 | 1路5V（红板继电器） | https://detail.tmall.com/item.htm?id=41231430731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 (https://detail.tmall.com/item.htm?id=593291231082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) | ¥4.24 | 1 | ¥4.24 | ¥13.74 | 朱镇 | 有
5 | 继电器 | 2路5V（红板继电器） | https://detail.tmall.com/item.htm?id=41231430731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 (https://detail.tmall.com/item.htm?id=593291231082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) | ¥9.50 | 1 | ¥9.50 |  | 朱镇 | 有
4 | 伊莱科直流推拉式电磁铁EML系列 | EML-1253B（12V）吸力45N | https://detail.tmall.com/item.htm?id=571228541835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 | ¥49.00 | 1 | ¥49.00 | ¥49.00 | 朱镇 | 有
5 | 梅花联轴器 | 外径25 长度30 孔04至12 | https://detail.tmall.com/item.htm?id=593291231082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 | ¥16.00 | 1 | ¥16.00 | ¥16.00 | 朱镇 | 有 | 8转12，开4键槽
19 | USB摄像头 |  | https://item.taobao.com/item.htm?id=567829133337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 | ¥82.00 | 1 | ¥82.00 | ¥82.00 | 朱镇 | 有
 | 集电环+碳刷 | 人字形刷架总成二组 SR20*50*34-2 | https://detail.tmall.com/item.htm?id=613640927612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 | ¥101.16 | 2 | ¥202.31 | ¥202.31 | 朱镇 | 有 | 需定制，具体尺寸根据实际确定
20 | 法兰轴承 | 3*8*4无挡边 | https://item.taobao.com/item.htm?id=558845796019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 | ¥19.00 | 2 | ¥38.00 | ¥38.00 | 朱镇 | 有 | 拍1件10颗
 | 304六角螺母 | M3 | https://detail.tmall.com/item.htm?id=597726726154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 | ¥2.60 | 1 | ¥2.60 | ¥2.60 | 朱镇 | 有 | 拍1件100颗
 | 304十字盘头螺钉 | M3*10 | https://detail.tmall.com/item.htm?id=537903695538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 | ¥3.50 | 1 | ¥3.50 | ¥5.60 | 朱镇 | 有 | 拍1件80颗
10 | 双通六角铜柱 | M3*16 | https://detail.tmall.com/item.htm?id=16626695446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 | ¥2.10 | 1 | ¥2.10 |  | 朱镇 | 有 | 拍1件10颗
20 | 57闭环步进电机 | 扭矩2.2Nm，编码线1.5m | https://item.taobao.com/item.htm?id=533749071599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 | ¥263.24 | 1 | ¥263.24 | ¥267.00 | 朱镇 | 有
20 | 57闭环步进电机支架 | 带4个螺丝 | https://item.taobao.com/item.htm?id=19085543855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 (https://item.taobao.com/item.htm?id=533749071599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) | ¥3.76 | 1 | ¥3.76 |  | 朱镇 | 有
20 | 3D打印 | 树脂材料光固化 | https://detail.tmall.com/item.htm?id=628981891558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 | ¥118.00 | 1 | ¥118.00 | ¥118.00 | 朱镇 | 有
10 | 304十字盘头螺钉 | M3*25 | https://detail.tmall.com/item.htm?id=537903695538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 | ¥3.60 | 1 | ¥3.60 | ¥14.30 | 朱镇 | 有 | 拍1件40颗
8 | 304十字盘头螺钉 | M5*8+垫片 | https://detail.tmall.com/item.htm?id=537903695538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 | ¥2.30 | 3 | ¥6.90 |  | 朱镇 | 有 | 拍1件20颗
 | 304垫圈 | M5*10*1 | https://detail.tmall.com/item.htm?id=15730068817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 | ¥1.90 | 2 | ¥3.80 |  | 朱镇 | 有 | 拍1件50颗
20 | 开关电源 | 24V20A500W输出线套餐 | https://detail.tmall.com/item.htm?id=613635946038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 | ¥90.00 | 1 | ¥90.00 | ¥90.00 | 朱镇 | 有
20 | 法兰轴承 | 3*8*4有挡边 | https://item.taobao.com/item.htm?id=558845796019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 | ¥18.00 | 1 | ¥18.00 | ¥18.00 | 朱镇 | 有 | 拍1件10颗
 | 316内六角螺丝 | M3*14 | https://detail.tmall.com/item.htm?id=556840829042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 | ¥6.80 | 1 | ¥6.80 | ¥6.80 | 朱镇 | 有 | 拍1件50颗
4 | 伊莱科直流推拉式电磁铁EML系列 | EML-1253B（12V）吸力45N | https://detail.tmall.com/item.htm?id=571228541835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 | ¥52.00 | 1 | ¥52.00 | ¥52.00 | 朱镇 | 有
20 | 法兰轴承 | 3*8*4有挡边 | https://item.taobao.com/item.htm?id=558845796019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 | ¥18.00 | 3 | ¥54.00 | ¥54.00 | 朱镇 | 有 | 拍1件10颗
 | 304十字盘头螺钉 | M2*10 | https://detail.tmall.com/item.htm?id=537903695538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 | ¥3.24 | 1 | ¥3.24 | ¥3.24 | 朱镇 | 有 | 拍1件100颗
10 | 双通六角铜柱 | M2*16 | https://detail.tmall.com/item.htm?id=637681799522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 | ¥5.40 | 1 | ¥5.40 | ¥5.40 | 朱镇 | 有 | 拍1件30颗
20 | 光轴 | 硬轴6*100mm | https://item.taobao.com/item.htm?id=15106654058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 (https://detail.tmall.com/item.htm?id=628981891558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) | ¥2.00 | 2 | ¥4.00 | ¥59.00 | 朱镇 | 有
20 | 光轴支架 | SK6 内径6 | https://item.taobao.com/item.htm?id=16936800487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 | ¥7.00 | 4 | ¥28.00 |  | 朱镇 | 有
20 | 锁紧环 | SCS6 内径6外径20厚度8 | https://item.taobao.com/item.htm?id=593599133092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 | ¥4.00 | 4 | ¥16.00 |  | 朱镇 | 有
20 | 运费 |  |  | ¥11.00 | 1 | ¥11.00 |  | 朱镇 | 有
20 | 不锈钢弹簧 | 线径0.8mm | https://detail.tmall.com/item.htm?id=628266591747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 | ¥5.00 | 1 | ¥5.00 | ¥11.00 | 朱镇 | 有 | 一包10只
20 | 不锈钢弹簧 | 线径1mm | https://item.taobao.com/item.htm?id=15106654058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 (https://detail.tmall.com/item.htm?id=628981891558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) | ¥6.00 | 1 | ¥6.00 |  | 朱镇 | 有 | 1包10只
 | 304六角螺母 | M4 | https://m.tb.cn/h.fZuOHYF?sm=1deb6b | ¥2.20 | 1 | ¥2.20 | ¥21.97 | 朱镇 | 有 | 拍1件50颗
 | 304六角螺母 | M5 | https://m.tb.cn/h.f0rTZwA?sm=b804d9 | ¥2.97 | 1 | ¥2.97 |  | 朱镇 | 有 | 拍1件50颗
 | 316内六角螺钉 | M4*12 | https://m.tb.cn/h.f0rhV2p?sm=cfd9c5 | ¥3.56 | 2 | ¥7.12 |  | 朱镇 | 有 | 拍1件20颗
11 | 316内六角螺钉 | M5*10 | https://m.tb.cn/h.faCiYGY?sm=2407e0 | ¥4.68 | 1 | ¥4.68 |  | 朱镇 | 有 | 拍1件20颗
11 | 316内六角螺钉 | M5*12 | https://m.tb.cn/h.faCiYGY?sm=2407e0 | ¥5.00 | 1 | ¥5.00 |  | 朱镇 | 有 | 拍1件20颗
5 | 继电器 | 2路5V（红板继电器） | https://detail.tmall.com/item.htm?id=41231430731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 (https://detail.tmall.com/item.htm?id=593291231082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) | ¥9.50 | 1 | ¥9.50 | ¥9.50 | 朱镇 | 有
5 | 梅花联轴器 | 外径25 长度30 孔04至12 | https://detail.tmall.com/item.htm?id=593291231082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 | ¥16.00 | 1 | ¥16.00 | ¥16.00 | 朱镇 | 有 | 8转12，开4键槽
20 | LM2596S DC-DC直流可调稳压模块 | 5A大功率75W | https://detail.tmall.com/item.htm?id=581544496424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 (https://item.taobao.com/item.htm?id=567829133337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) | ¥15.23 | 1 | ¥15.23 | ¥15.23 | 朱镇 | 有
4 | 伊莱科直流推拉式电磁铁EML系列 | EML-1253B（12V）吸力45N | https://detail.tmall.com/item.htm?id=571228541835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 | ¥52.00 | 1 | ¥52.00 | ¥52.00 | 朱镇 | 有
20 | 57闭环步进电机 | 扭矩2.2Nm，编码线1.5m | https://item.taobao.com/item.htm?id=533749071599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 | ¥252.04 | 1 | ¥252.04 | ¥259.42 | 朱镇 | 有
20 | 57闭环步进电机支架 | 带4个螺丝 | https://item.taobao.com/item.htm?id=19085543855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 (https://item.taobao.com/item.htm?id=533749071599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) | ¥3.38 | 1 | ¥3.38 |  | 朱镇 | 有
4 | 运费 |  |  | ¥4.00 | 1 | ¥4.00 |  | 朱镇 | 有
20 | 3D打印 | 树脂材料光固化 | https://detail.tmall.com/item.htm?id=628981891558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 | ¥118.00 | 1 | ¥118.00 | ¥118.00 | 朱镇 | 有
20 | 塔簧 | 1*12*25*40*9 | https://m.tb.cn/h.fbn7K2Z?sm=a1d823 | ¥2.00 | 2 | ¥4.00 | ¥22.00 | 朱镇 | 有
20 | 塔簧 | 1*12*22*26*6 | https://m.tb.cn/h.fbn7K2Z?sm=a1d823 | ¥2.00 | 2 | ¥4.00 |  | 朱镇 | 有
20 | 塔簧 | 1*18*23*30*6 | https://m.tb.cn/h.fbn7K2Z?sm=a1d823 | ¥2.00 | 2 | ¥4.00 |  | 朱镇 | 有
20 | 运费 |  |  | ¥10.00 | 1 | ¥10.00 |  | 朱镇 | 有
16 | 滑块螺母 | 欧标20M4 | https://detail.tmall.com/item.htm?id=576220220243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 (https://m.tb.cn/h.4zXMLN4?sm=ecf60e) | ¥0.72 | 20 | ¥14.40 | ¥63.00 | 朱镇 | 有
17 | 滑块螺母 | 欧标20M5 | https://detail.tmall.com/item.htm?id=576220220243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 (https://m.tb.cn/h.4zXMLN4?sm=ecf60e) | ¥0.72 | 20 | ¥14.40 |  | 朱镇 | 有
17 | T型螺母 | 欧标20M5 | https://m.tb.cn/h.f0rPjI9?sm=e39ee0 | ¥0.58 | 20 | ¥11.60 |  | 朱镇 | 有
 | 运费 |  |  | ¥22.60 | 1 | ¥22.60 |  | 朱镇 | 有
20 | 硅胶条 | 长150mm 宽100mm 厚0.3 0.5 0.7 0.9mm | https://m.tb.cn/h.fZuv0F6?sm=3e91c3 | ¥120.00 | 1 | ¥120.00 | ¥120.00 | 朱镇 | 有 | 买错尺寸了，应该买长15mm宽10mm，留给下一届用
20 | 偏振片 | 15*15cm 0.17mm厚光面无胶 | https://m.tb.cn/h.fbnNVB4?sm=58ee10 | ¥39.90 | 1 | ¥39.90 | ¥39.90 | 朱镇 | 有
17 | T型螺母 | 欧标20M5 | https://m.tb.cn/h.f0rPjI9?sm=e39ee0 | ¥0.58 | 20 | ¥11.60 | ¥65.17 | 朱镇 | 有
15 | 角码 | 2020角码（含紧固件） | https://detail.tmall.com/item.htm?id=576621463575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 | ¥1.90 | 20 | ¥38.00 |  | 朱镇 | 有
 | 运费 |  |  | ¥15.57 | 1 | ¥15.57 |  | 朱镇 | 有
7 | 304垫圈 | M4*12*1 | https://m.tb.cn/h.faC95mI?sm=b88fbd | ¥6.49 | 1 | ¥6.49 | ¥10.48 | 朱镇 | 有 | 拍1件50颗
7 | 304垫圈 | M5*12*1 | https://m.tb.cn/h.faC95mI?sm=b88fbd | ¥3.99 | 1 | ¥3.99 |  | 朱镇 | 有 | 拍1件50颗
20 | 导线 | 0.3平方红色100米 | https://m.tb.cn/h.f1P3JEc?sm=d2d195 | ¥32.00 | 1 | ¥32.00 | ¥32.00 | 朱镇 | 有
4 | 伊莱科直流推拉式电磁铁EML系列 | EML-1564B（24V）吸力65N | https://m.tb.cn/h.fYnO0FI?sm=4fb968 | ¥55.00 | 2 | ¥110.00 | ¥133.00 | 朱镇 | 有
 | 运费 |  |  | ¥23.00 | 1 | ¥23.00 |  | 朱镇 | 有
 | 电源线 | 三脚带端子 | https://m.tb.cn/h.fciky9T?sm=b525a8 | ¥13.00 | 1 | ¥13.00 | ¥31.00 | 朱镇 | 有 | 拍1件200颗
20 | 开关电源 | 12V2A25W | https://m.tb.cn/h.fYyTEib?sm=e93f20 | ¥18.00 | 1 | ¥18.00 |  | 朱镇 | 有 | 拍1件100颗
9 | 304圆头螺钉 | M2*12 | https://m.tb.cn/h.f1Ph8Pu?sm=c90a37 | ¥7.60 | 1 | ¥7.60 | ¥39.55 | 朱镇 | 有 | 拍1件50颗
9 | 304圆头螺钉 | M3*12 | https://m.tb.cn/h.f1Ph8Pu?sm=c90a37 | ¥4.30 | 1 | ¥4.30 |  | 朱镇 | 有 | 拍1件20颗
11 | 304圆头螺钉 | M4*20 | https://m.tb.cn/h.fciNrLV?sm=0a8ff7 | ¥5.00 | 1 | ¥5.00 |  | 朱镇 | 有 | 拍1件50颗
10 | 双通六角铜柱 | M2*20 | https://m.tb.cn/h.f1P7Zo1?sm=b94753 | ¥8.40 | 1 | ¥8.40 |  | 朱镇 | 有 | 石家庄发货
10 | 双通六角铜柱 | M3*20 | https://m.tb.cn/h.f1P7Zo1?sm=b94753 | ¥14.25 | 1 | ¥14.25 |  | 朱镇 | 有 | 上海发货
20 | 3D打印 | 树脂材料光固化 | https://m.tb.cn/h.f1PievY?sm=039839 | ¥35.00 | 1 | ¥35.00 | ¥35.00 | 朱镇 | 有 | 商家发成鱼眼的，以后记得要平角的，不要鱼眼镜头
20 | 3D打印 | 树脂材料光固化 | https://m.tb.cn/h.f1PRmgb?sm=4d3e95 | ¥275.00 | 1 | ¥275.00 | ¥275.00 | 朱镇 | 有
20 | AHD摄像头 | 平头720P | https://m.tb.cn/h.fbJVoHa?sm=a8f405 | ¥79.00 | 4 | ¥316.00 | ¥339.00 | 朱镇 | 有
20 | 运费 |  |  | ¥23.00 | 1 | ¥23.00 |  | 朱镇 | 有
20 | 阿卡西斯采集卡 | AHD4路 | https://m.tb.cn/h.f1PPva7?sm=e5ac3f | ¥432.78 | 1 | ¥432.78 | ¥432.78 | 朱镇 | 有
 | 运费 |  |  | ¥15.00 | 1 | ¥15.00 | ¥15.00 | 朱镇 | 有
 | 电源线 | 三脚带端子 | https://m.tb.cn/h.fciky9T?sm=b525a8 | ¥13.00 | 2 | ¥26.00 | ¥62.00 | 朱镇 | 有
 | 开关电源 | 12V10A120W | https://m.tb.cn/h.f1PURZ3?sm=9921e8 | ¥36.00 | 1 | ¥36.00 |  | 朱镇 | 有
 | 电源线 | 三脚带端子 | https://m.tb.cn/h.fciky9T?sm=b525a8 | ¥13.00 | 3 | ¥39.00 | ¥225.00 | 朱镇 | 有
 | 开关电源 | 12V10A120W | https://m.tb.cn/h.f1PURZ3?sm=9921e8 | ¥36.00 | 1 | ¥36.00 |  | 朱镇 | 有 | 石家庄发货
20 | 开关电源 | 24V20A500W | https://m.tb.cn/h.fYyTEib?sm=e93f20 | ¥75.00 | 2 | ¥150.00 |  | 朱镇 | 有
20 | 3D打印 | 树脂材料光固化 | https://m.tb.cn/h.f1PievY?sm=039839 | ¥100.00 | 1 | ¥100.00 | ¥100.00 | 朱镇 | 有
20 | BNC延长线 | 0.5m；bnc公对公（镀金） | https://m.tb.cn/h.fYMYMin?sm=02f85e | ¥38.20 | 1 | ¥38.20 | ¥38.20 | 朱镇 | 有
5 | 继电器 | 2路24V（红板继电器） | https://m.tb.cn/h.faCg56e?sm=b1ea0e | ¥10.33 | 6 | ¥62.00 | ¥92.00 | 朱镇 | 有
5 | 运费 |  |  | ¥30.00 | 1 | ¥30.00 |  | 朱镇 | 有 | 去老校区拿快递，寄错了
20 | 圣手传奇三阶魔方 |  | https://item.m.jd.com/product/5098407.html?ad_od=share&gx=RnExwjJYPDbQw9RP--txVY-68Rbuz_G3s_mw | ¥9.42 | 4 | ¥37.68 | ¥37.68 | 朱镇 | 有 | 去老校区拿快递，寄错了
20 | 滴滴出行 | 新校区—老校区 |  | ¥53.36 | 1 | ¥53.36 | ¥53.36 | 朱镇 | 有
20 | 滴滴出行 | 老校区—新校区 |  | ¥60.08 | 1 | ¥60.08 | ¥60.08 | 朱镇 | 有
20 | 顺丰 |  |  | ¥65.00 | 1 | ¥65.00 | ¥65.00 | 朱镇 | 有
 |  |  |  |  |  |  |  | 总价
 |  |  |  |  |  | 合计 |  | ¥4408.94

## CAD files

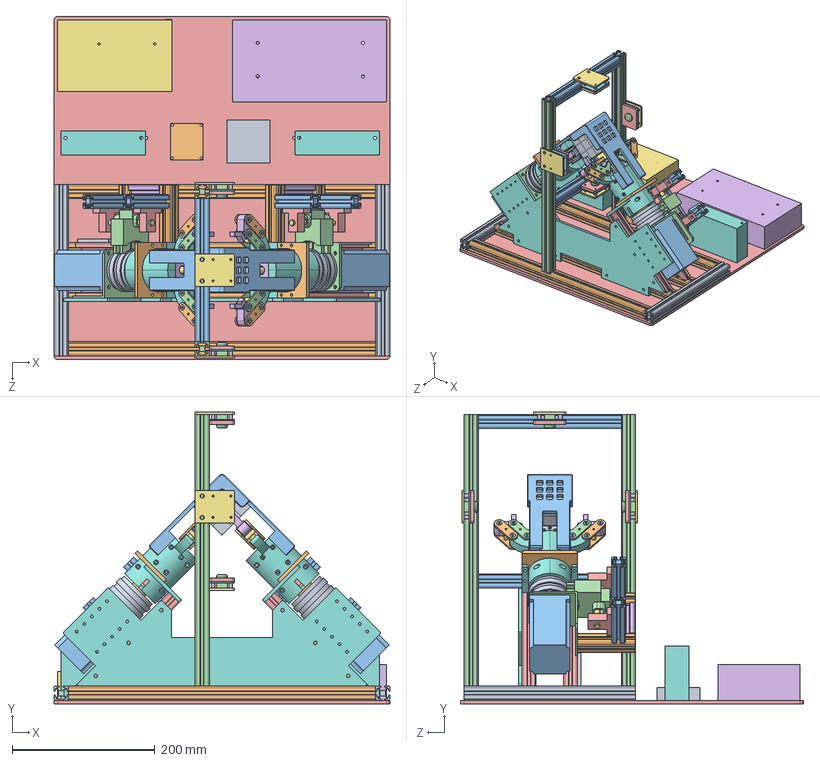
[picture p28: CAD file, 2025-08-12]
CAD_models/三维模型/双臂总装.SLDASM
470.0 x 408.0 x 480.0 mm
魔方
弹性联轴器 x 2
电机 x 2
电机座 x 2
主骨架侧铝203.5 x 4
电磁铁外壳 x 2
电磁铁内芯 x 2
手爪1 x 4
电磁铁推块 x 2
手指1 x 8
法兰杯式轴承 x 32
手指2 x 8
M2铜柱 x 4
手指-指尖 x 4
铜柱-16 x 8
支撑板 x 2
滑环 x 2
主骨架500 x 4
摄像头铝200 x 2
摄像头 x 4
下亚克力 x 4
尼龙套 x 16
上亚克力 x 4
下亚克力2 x 4
摄像头铝240 x 2
滑环铝1 x 4
滑环铝2 x 4
滑环碳刷 x 2
光轴支架 x 4
滑环铝3 x 2
光轴100 x 2
总固定板
副固定板
支撑板2 x 2
摄像头铝496 x 2
底板
500W电源
120W电源
驱动板 x 2
PCB
继电器

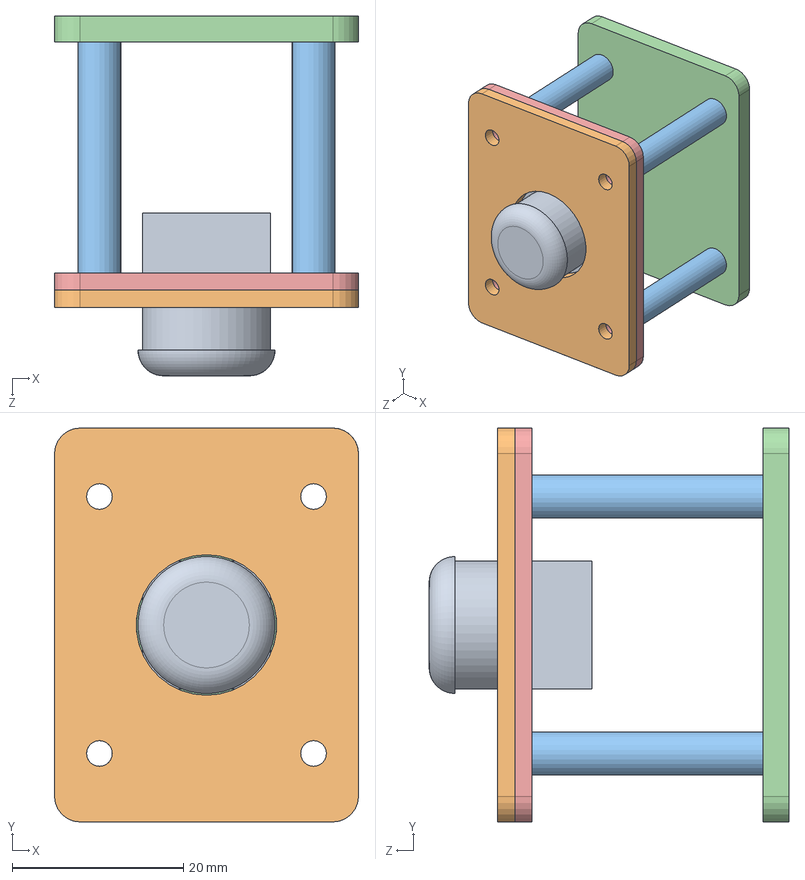
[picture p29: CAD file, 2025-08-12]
CAD_models/三维模型/摄像头组件/摄像头组件.SLDASM
35.5 x 46.0 x 42.0 mm
摄像头
下亚克力
尼龙套 x 4
上亚克力
下亚克力2

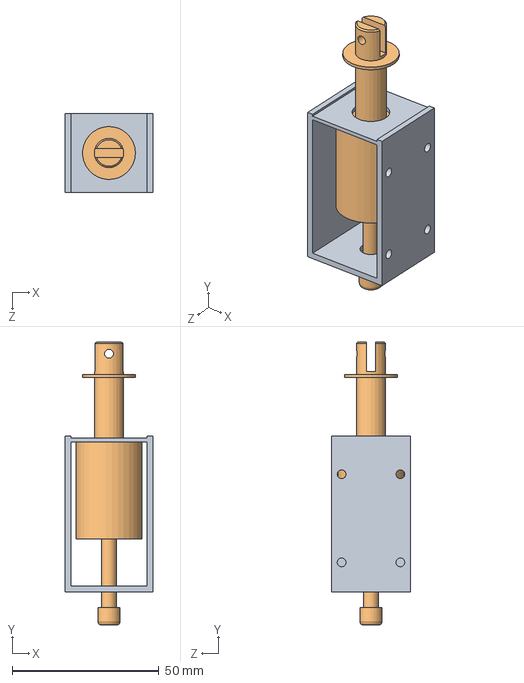
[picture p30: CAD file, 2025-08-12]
CAD_models/三维模型/单个手臂/手臂 小/电磁铁.SLDASM
30.0 x 96.3 x 27.0 mm
电磁铁外壳
电磁铁内芯

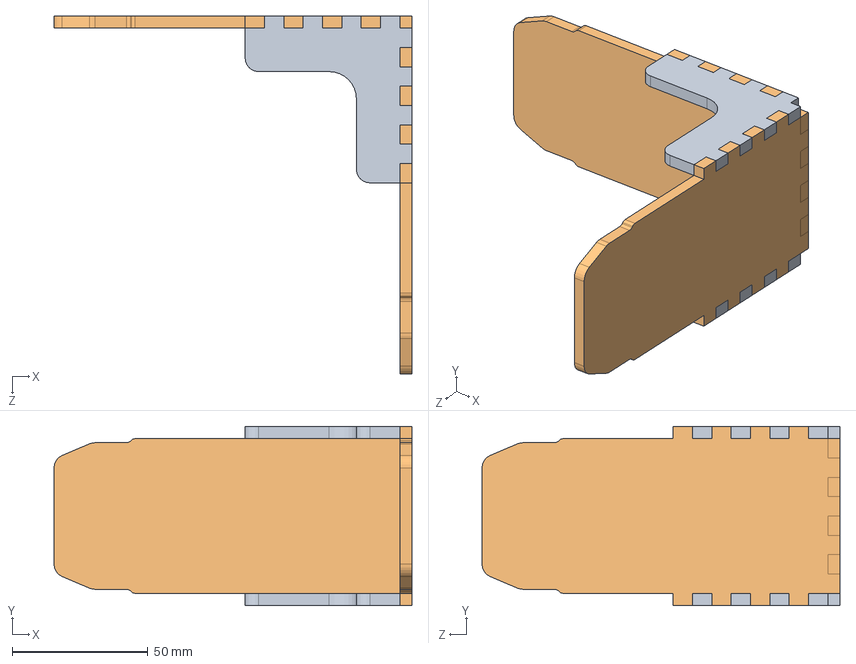
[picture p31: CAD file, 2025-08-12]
CAD_models/三维模型/发车架/发车架总装配.SLDASM
131.9 x 66.0 x 131.9 mm
侧板 x 2
插入内板 x 2

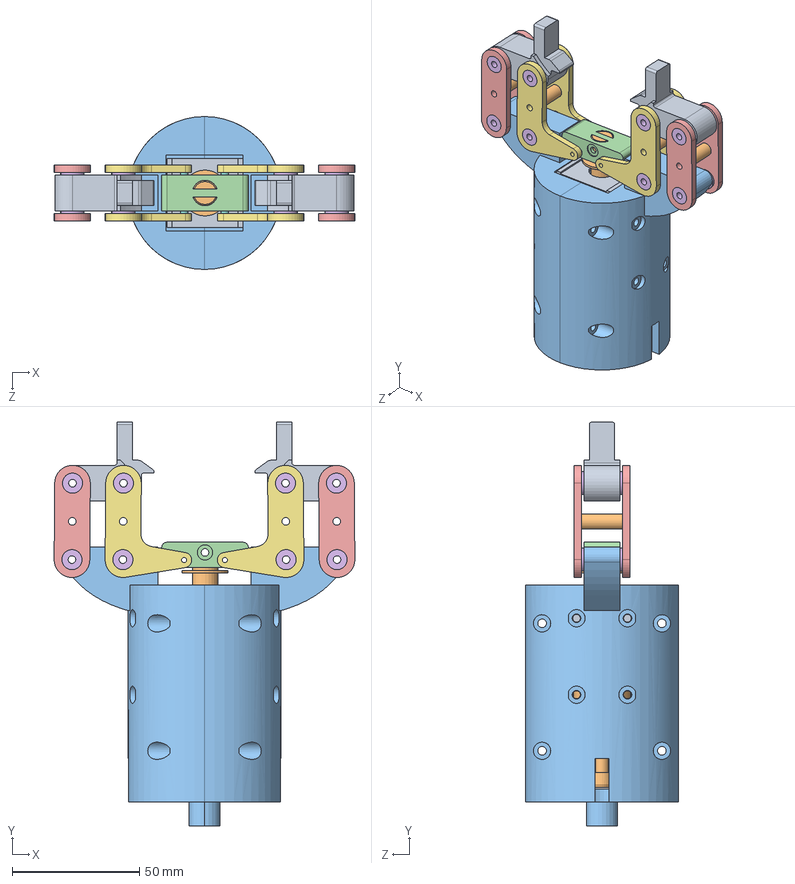
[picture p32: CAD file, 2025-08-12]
CAD_models/三维模型/单个手臂/手臂 小/手爪总装配.SLDASM
118.0 x 158.5 x 60.0 mm
电磁铁外壳
电磁铁内芯
手爪1 x 2
电磁铁推块
手指1 x 4
法兰杯式轴承 x 16
手指2 x 4
M2铜柱 x 2
手指-指尖 x 2
铜柱-16 x 4

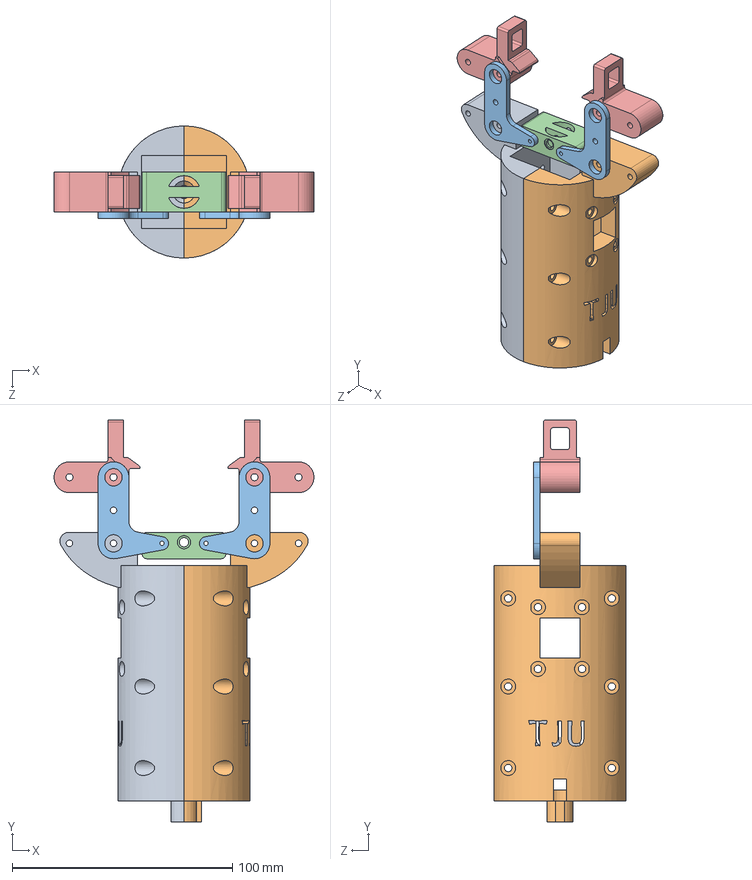
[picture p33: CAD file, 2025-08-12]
CAD_models/三维模型/修改后的手爪模型/装配体1.SLDASM
117.9 x 182.5 x 60.0 mm
手爪1_new
手爪2_new
手指2_new x 2
电磁铁推块_new
手指-指尖_new x 2

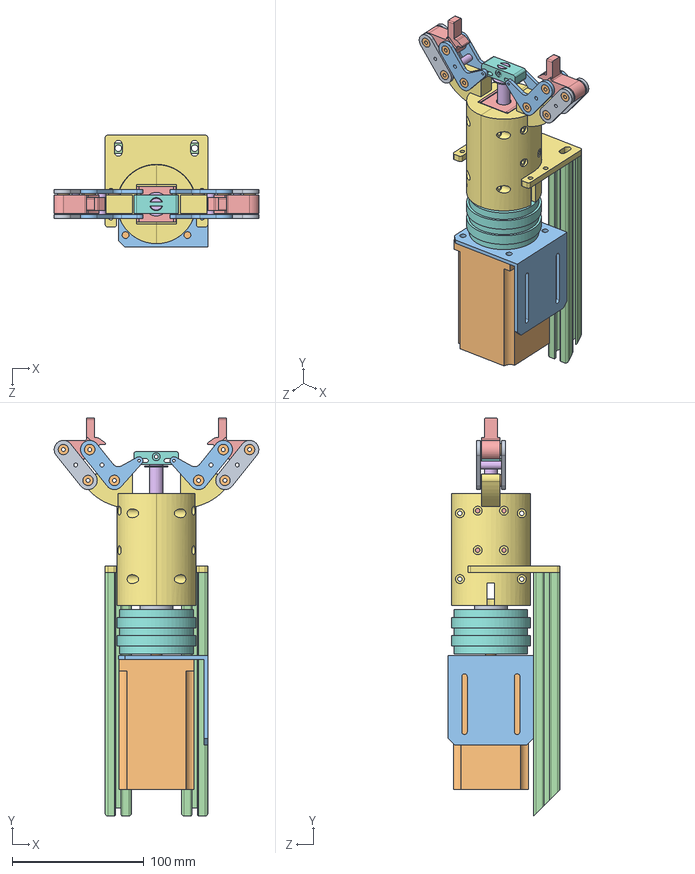
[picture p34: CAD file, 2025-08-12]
CAD_models/三维模型/单个手臂/手抓.SLDASM
155.5 x 302.4 x 85.0 mm
弹性联轴器
电机
电机座
主骨架侧铝203.5 x 2
电磁铁外壳
电磁铁内芯
手爪1 x 2
电磁铁推块
手指1 x 4
法兰杯式轴承 x 16
手指2 x 4
M2铜柱 x 2
手指-指尖 x 2
铜柱-16 x 4
支撑板
滑环

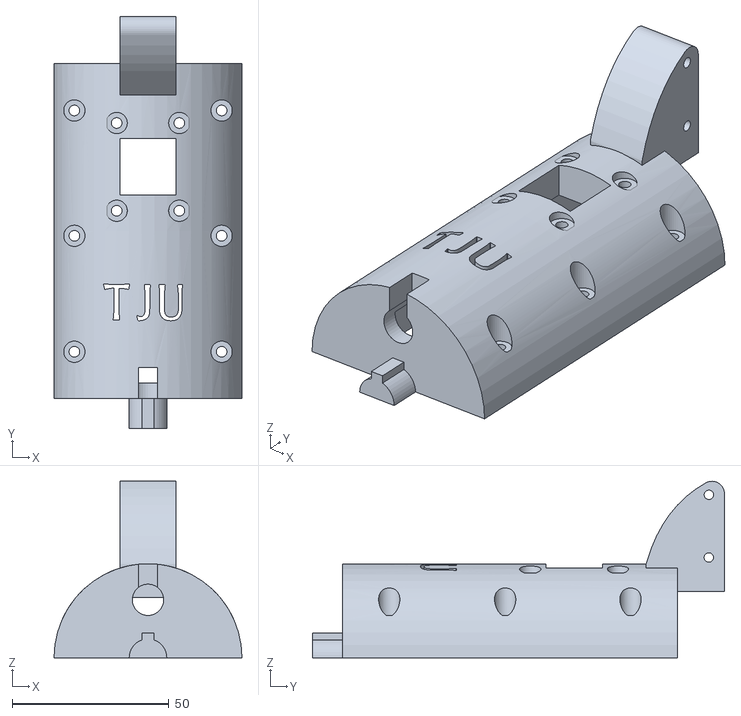
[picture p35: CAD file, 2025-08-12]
CAD_models/3D打印_new/2×手爪2_new.STL
60.0 x 131.5 x 56.3

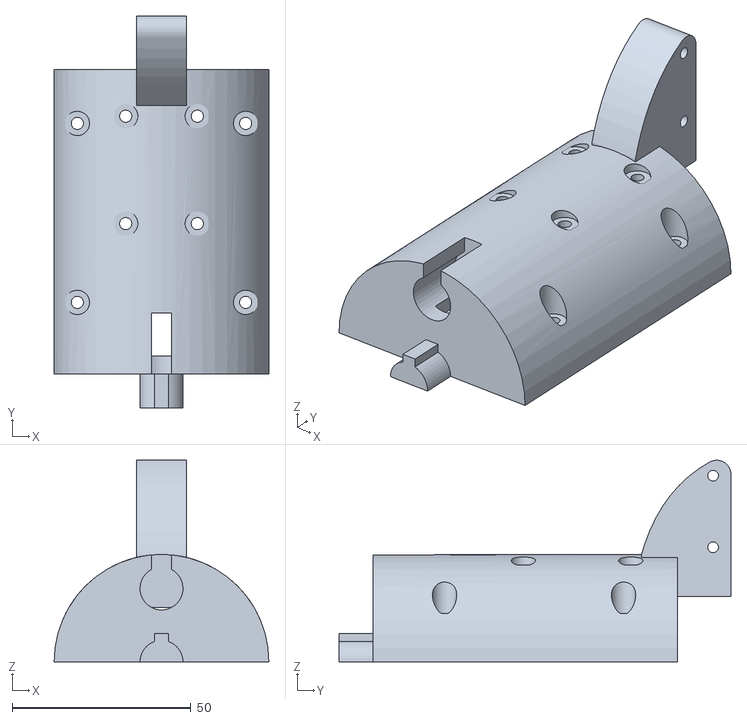
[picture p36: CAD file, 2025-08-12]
CAD_models/3D打印件/1×手爪2.STL
60.0 x 109.5 x 56.3

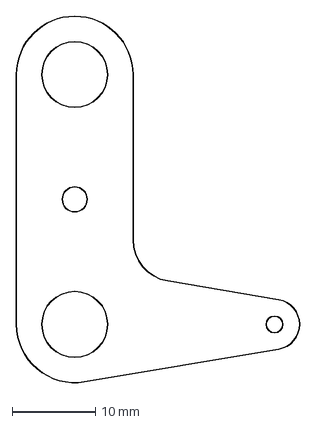
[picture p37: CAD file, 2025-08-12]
CAD_models/DXF/8×手指2_3mm.DXF
34.0 x 44.2 mm

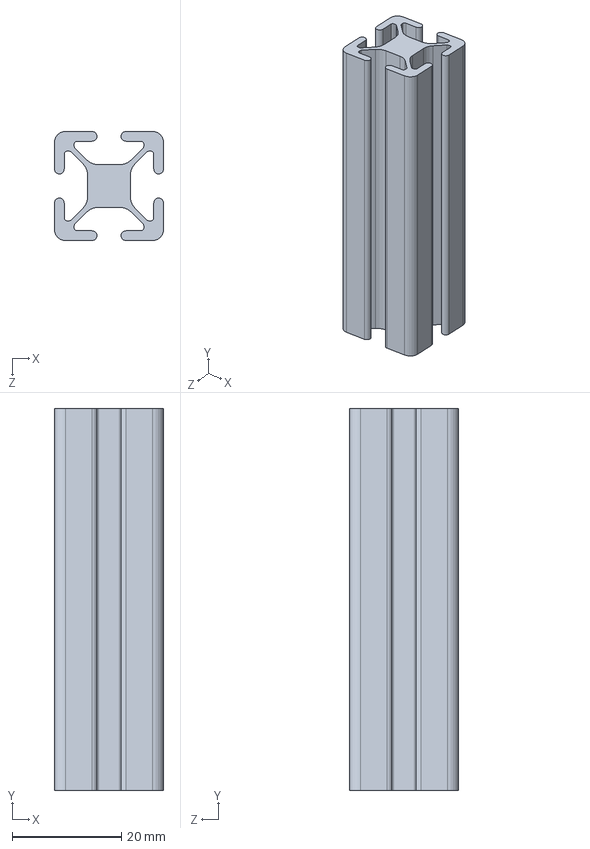
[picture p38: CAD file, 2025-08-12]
CAD_models/三维模型/主骨架/滑环铝2.SLDPRT
20.0 x 70.0 x 20.0 mm

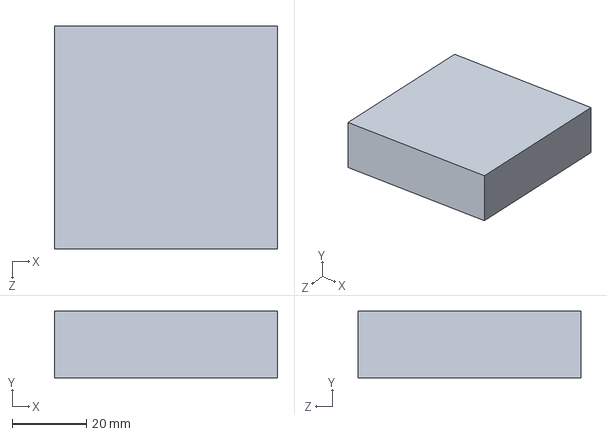
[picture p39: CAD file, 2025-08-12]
CAD_models/三维模型/修改后的手爪模型/PCB.SLDPRT
60.0 x 18.0 x 60.0 mm

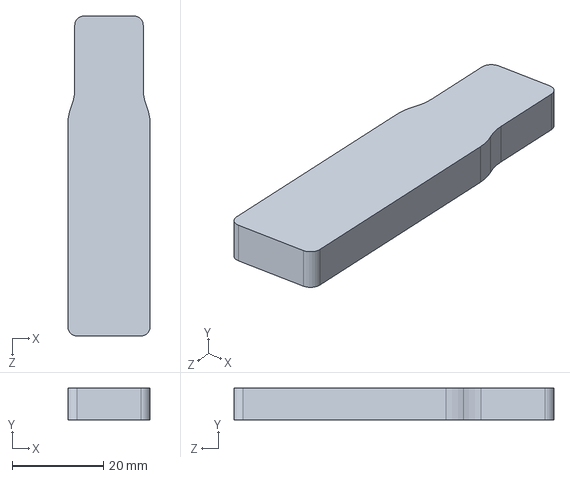
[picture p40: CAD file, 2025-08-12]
CAD_models/三维模型/单个手臂/亚克力手指.SLDPRT
18.0 x 7.00 x 70.0 mm

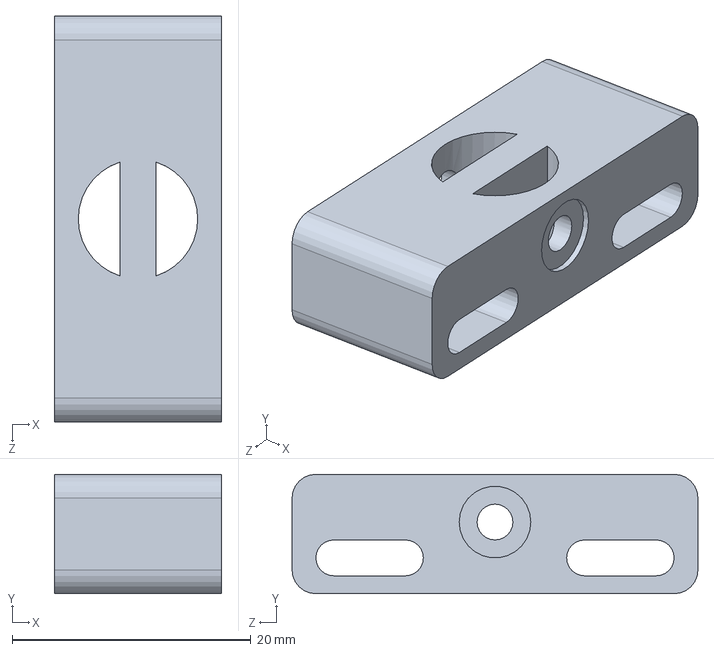
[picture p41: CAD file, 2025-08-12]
CAD_models/三维模型/单个手臂/手臂 小/电磁铁推块.SLDPRT
14.0 x 10.0 x 34.0 mm

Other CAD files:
CAD_models/三维模型/单个手臂/手臂 小/电磁铁-固定魔方.SLDASM
CAD_models/三维模型/发车架/发车架切割.dxf
CAD_models/3D打印_new/4×手指-指尖_new.STL
CAD_models/3D打印件/2×指尖.STL
CAD_models/3D打印_new/2×手爪1_new.STL
CAD_models/3D打印_new/2×电磁铁推块_new.STL
CAD_models/3D打印_new/4×手指-指尖_new2.STL
CAD_models/3D打印_new/手指-指尖2_new.STL
CAD_models/3D打印_new/手指-指尖_new.STL
CAD_models/3D打印件/1×手爪1.STL
CAD_models/3D打印件/1×电磁铁推块.STL
CAD_models/DXF/1×总固定板_5mm.DXF
CAD_models/DXF/2×副固定板_5mm.DXF
CAD_models/DXF/2×小板.DXF
CAD_models/DXF/2×支撑板1_5mm.DXF
CAD_models/DXF/2×支撑板2_5mm.DXF
CAD_models/DXF/2×支撑板2_new_5mm.DXF
CAD_models/DXF/3×锁紧环.DXF
CAD_models/DXF/4×上亚克力_3mm.DXF
CAD_models/DXF/4×下亚克力2_2mm.DXF
CAD_models/DXF/4×下亚克力2_new_3mm.DXF
CAD_models/DXF/4×下亚克力_5mm.DXF
CAD_models/DXF/8×手指1 _3mm.DXF
CAD_models/DXF/8×手指2_new_3mm.DXF
CAD_models/DXF/上底板.DXF
CAD_models/DXF/锁紧环.DXF
CAD_models/三维模型/主骨架/主骨架500.SLDPRT
CAD_models/三维模型/主骨架/光轴100.SLDPRT
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

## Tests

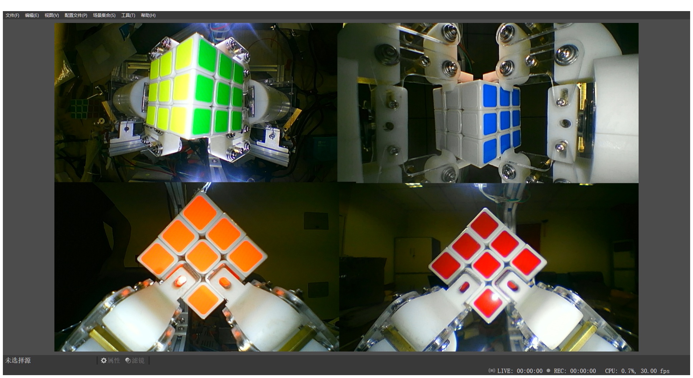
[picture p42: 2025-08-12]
Codes/cube_2颜色识别/testss.jpg

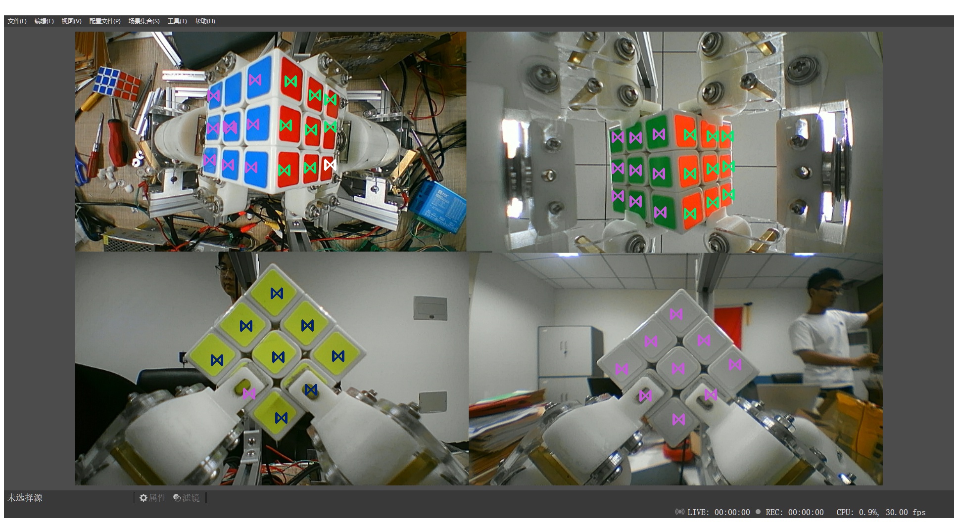
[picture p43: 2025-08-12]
Codes/cube_2颜色识别/test_res.jpg

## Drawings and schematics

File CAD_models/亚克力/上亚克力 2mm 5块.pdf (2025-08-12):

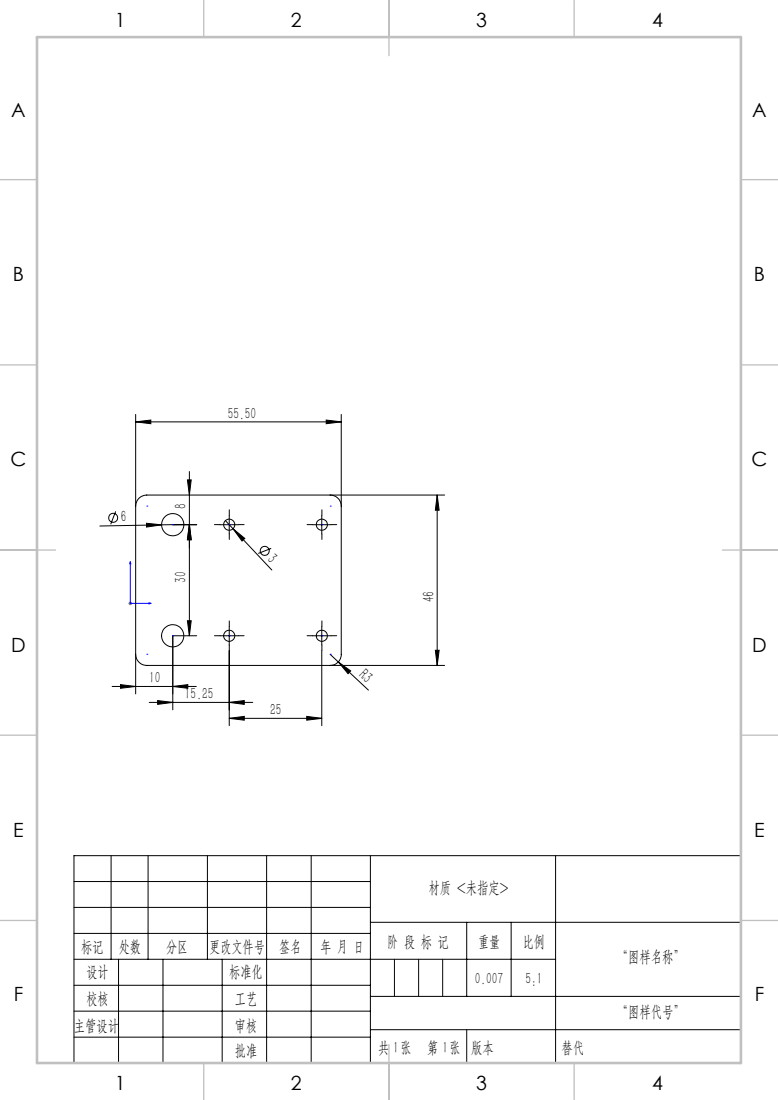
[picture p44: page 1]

材质 <未指定>

阶 段 标 记 | 重量 | 比例 | “图样名称”

标记 | 处数 | 分区 | 更改文件号 | 签名 | 年 月 日
设计 | | | 标准化 | | | 0.007 | 5:1
校核 | | | 工艺
主管设计 | | | 审核

“图样代号”

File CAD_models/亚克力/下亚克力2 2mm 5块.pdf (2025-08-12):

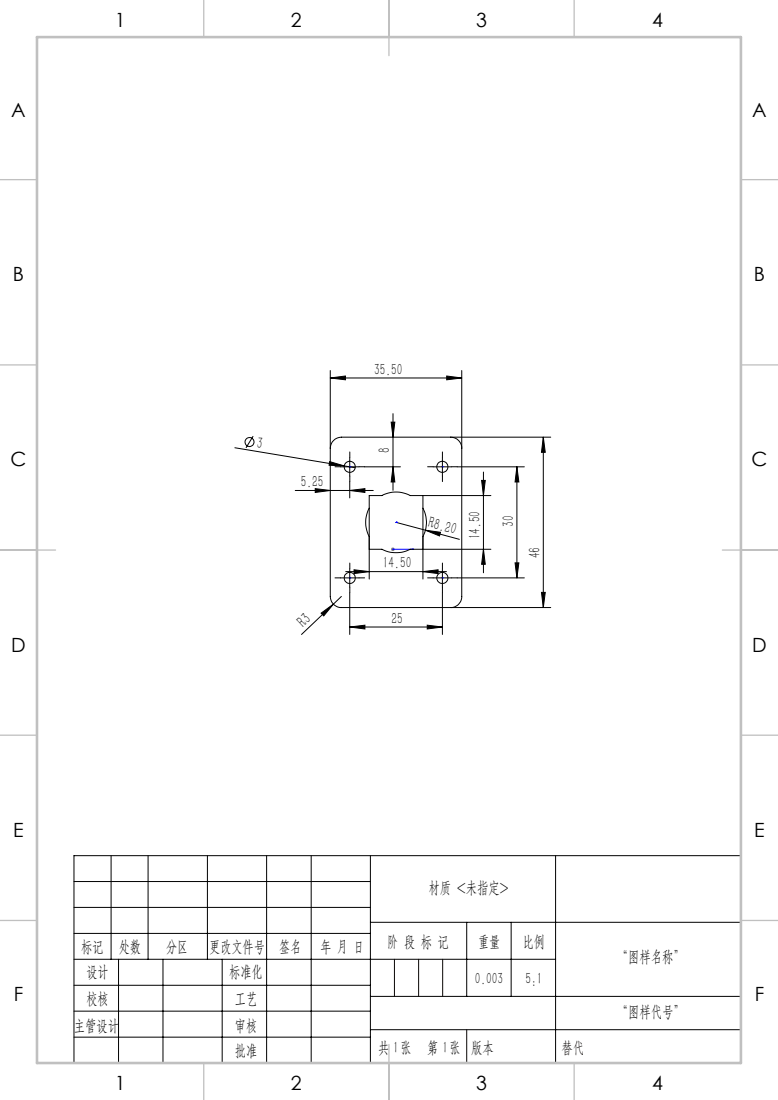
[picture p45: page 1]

材质 <未指定>

阶 段 标 记 | 重量 | 比例 | “图样名称”

标记 | 处数 | 分区 | 更改文件号 | 签名 | 年 月 日
设计 | | | 标准化 | | | 0.003 | 5:1
校核 | | | 工艺
主管设计 | | | 审核

“图样代号”

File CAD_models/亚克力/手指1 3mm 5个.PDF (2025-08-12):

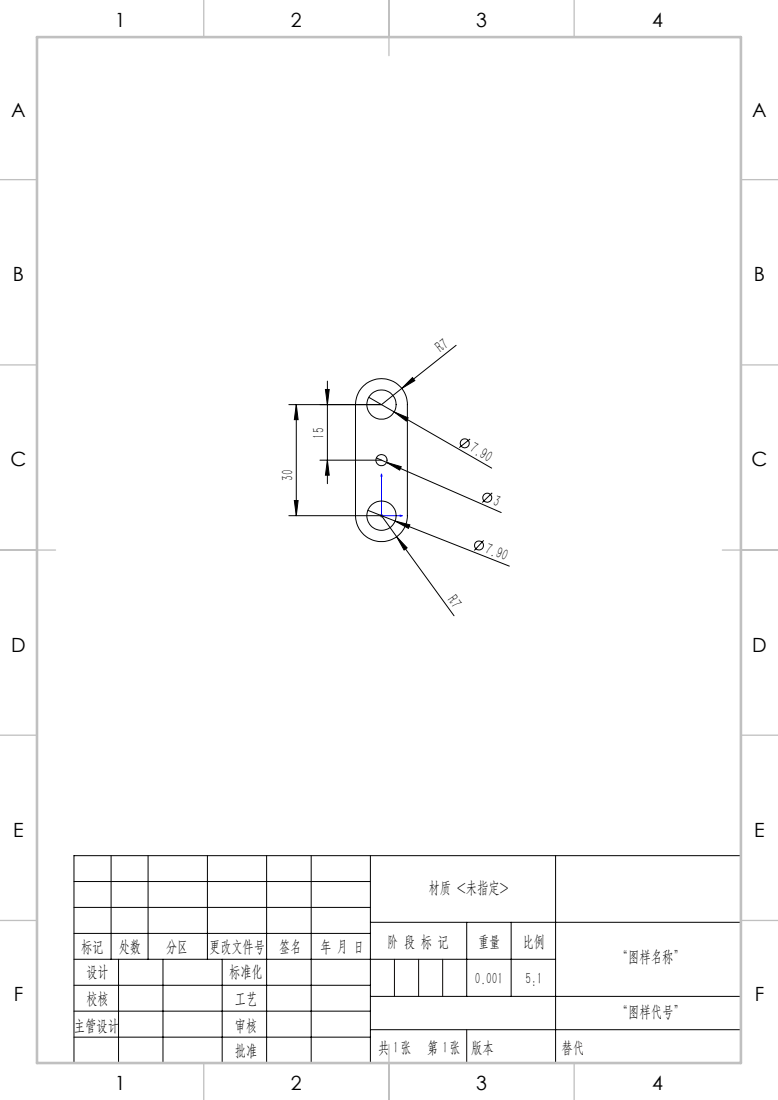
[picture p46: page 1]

材质 <未指定>

阶 段 标 记 | 重量 | 比例 | “图样名称”

标记 | 处数 | 分区 | 更改文件号 | 签名 | 年 月 日
设计 | | | 标准化 | | | 0.001 | 5:1
校核 | | | 工艺
主管设计 | | | 审核

“图样代号”

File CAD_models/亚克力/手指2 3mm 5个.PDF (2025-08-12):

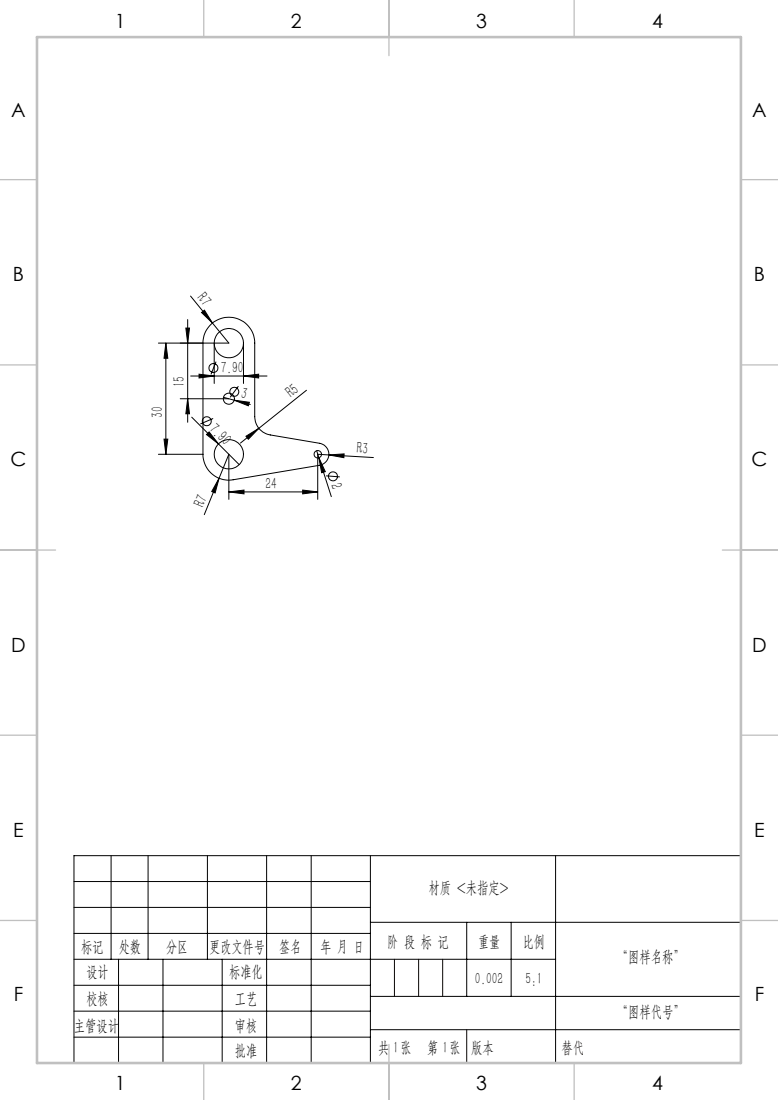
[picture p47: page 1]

材质 <未指定>

阶 段 标 记 | 重量 | 比例 | “图样名称”

标记 | 处数 | 分区 | 更改文件号 | 签名 | 年 月 日
设计 | | | 标准化 | | | 0.002 | 5:1
校核 | | | 工艺
主管设计 | | | 审核

“图样代号”

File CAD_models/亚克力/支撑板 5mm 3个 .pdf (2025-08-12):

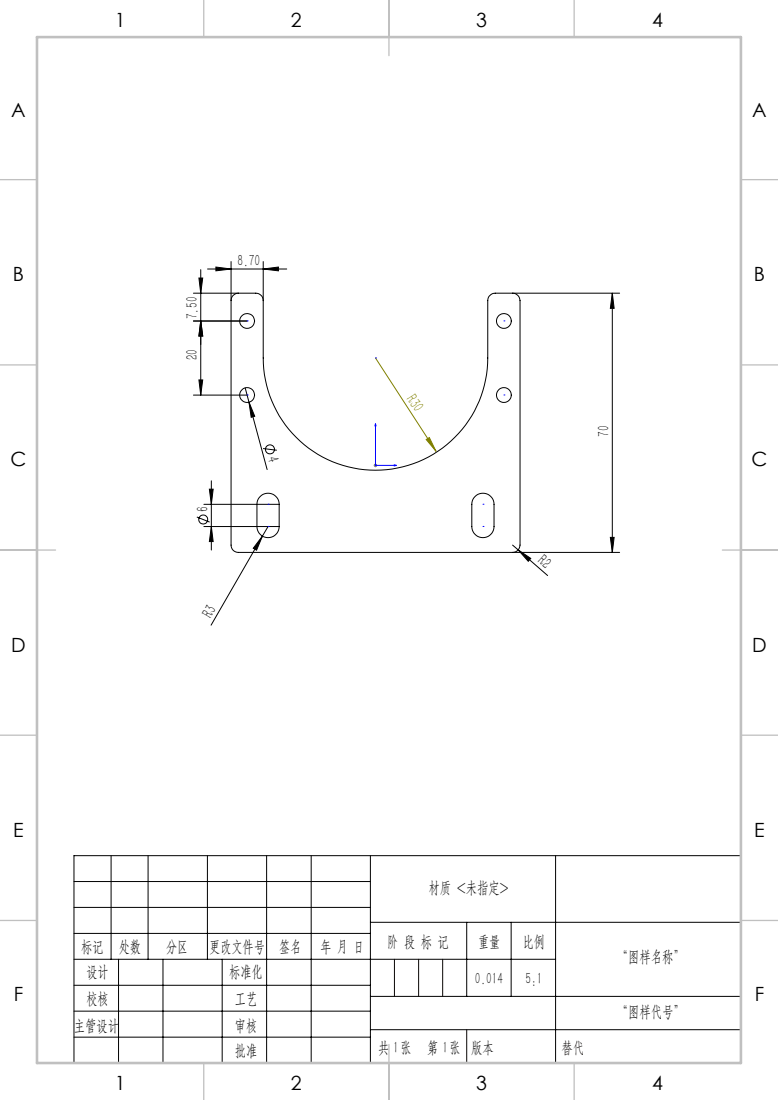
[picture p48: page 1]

材质 <未指定>

阶 段 标 记 | 重量 | 比例 | “图样名称”

标记 | 处数 | 分区 | 更改文件号 | 签名 | 年 月 日
设计 | | | 标准化 | | | 0.014 | 5:1
校核 | | | 工艺
主管设计 | | | 审核

“图样代号”

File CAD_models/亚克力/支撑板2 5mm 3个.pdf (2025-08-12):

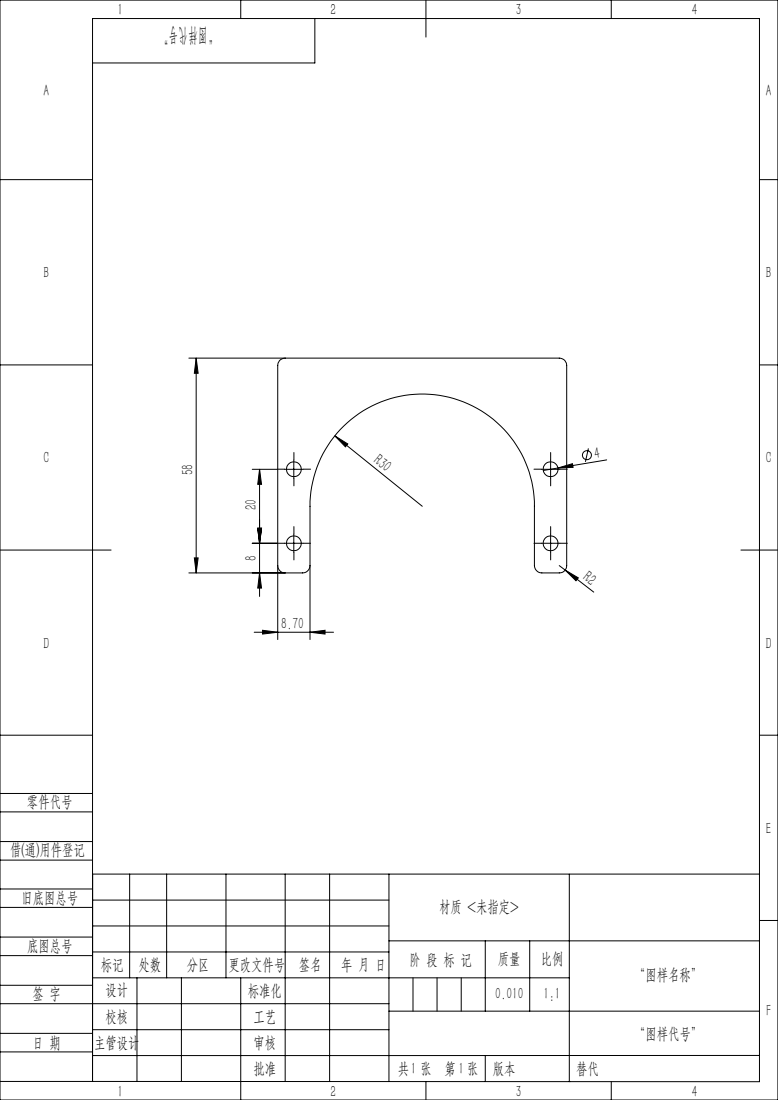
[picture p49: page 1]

材质 <未指定>

阶 段 标 记 | 质量 | 比例 | “图样名称”

标记 | 处数 | 分区 | 更改文件号 | 签名 | 年 月 日
设计 | | | 标准化 | | | | | | 0.010 | 1:1
校核 | | | 工艺
主管设计 | | | 审核

“图样代号”

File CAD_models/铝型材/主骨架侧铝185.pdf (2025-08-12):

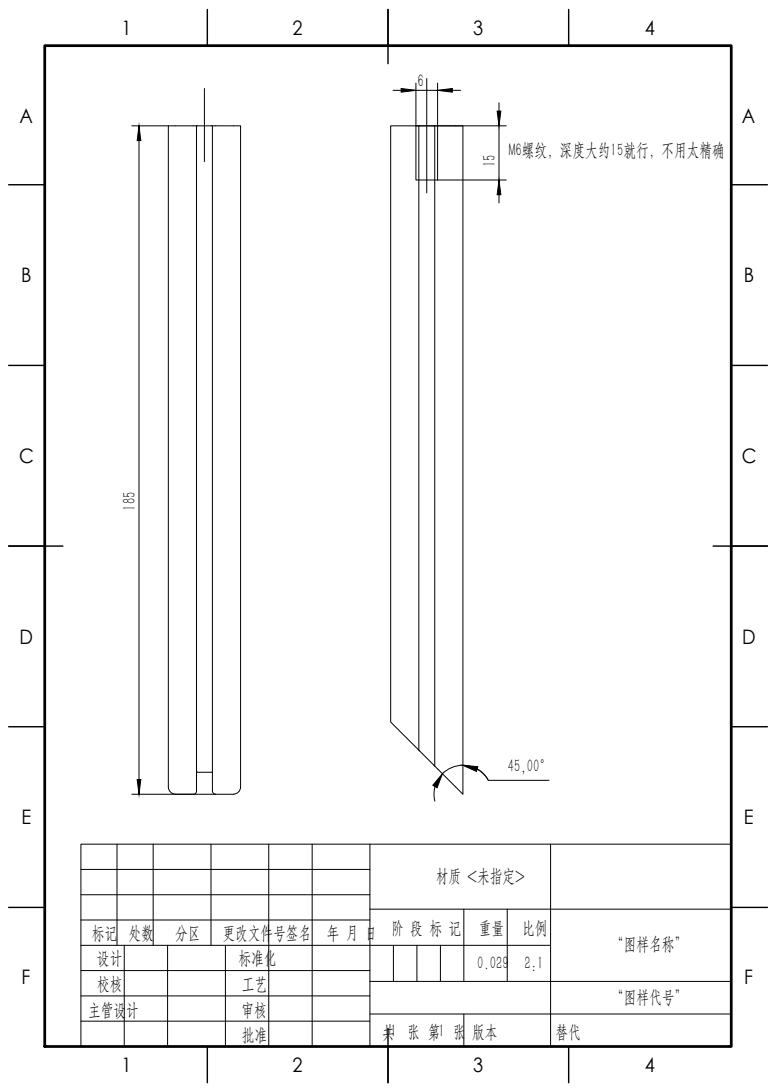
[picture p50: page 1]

材质 <未指定>

阶 段 标 记 | 重量 | 比例 | “图样名称”

标记 | 处数 | 分区 | 更改文件号签名 | 年 月 日
设计 | | | 标准化 | | 0.029 | 2:1
校核 | | | 工艺
主管设计

“图样代号”

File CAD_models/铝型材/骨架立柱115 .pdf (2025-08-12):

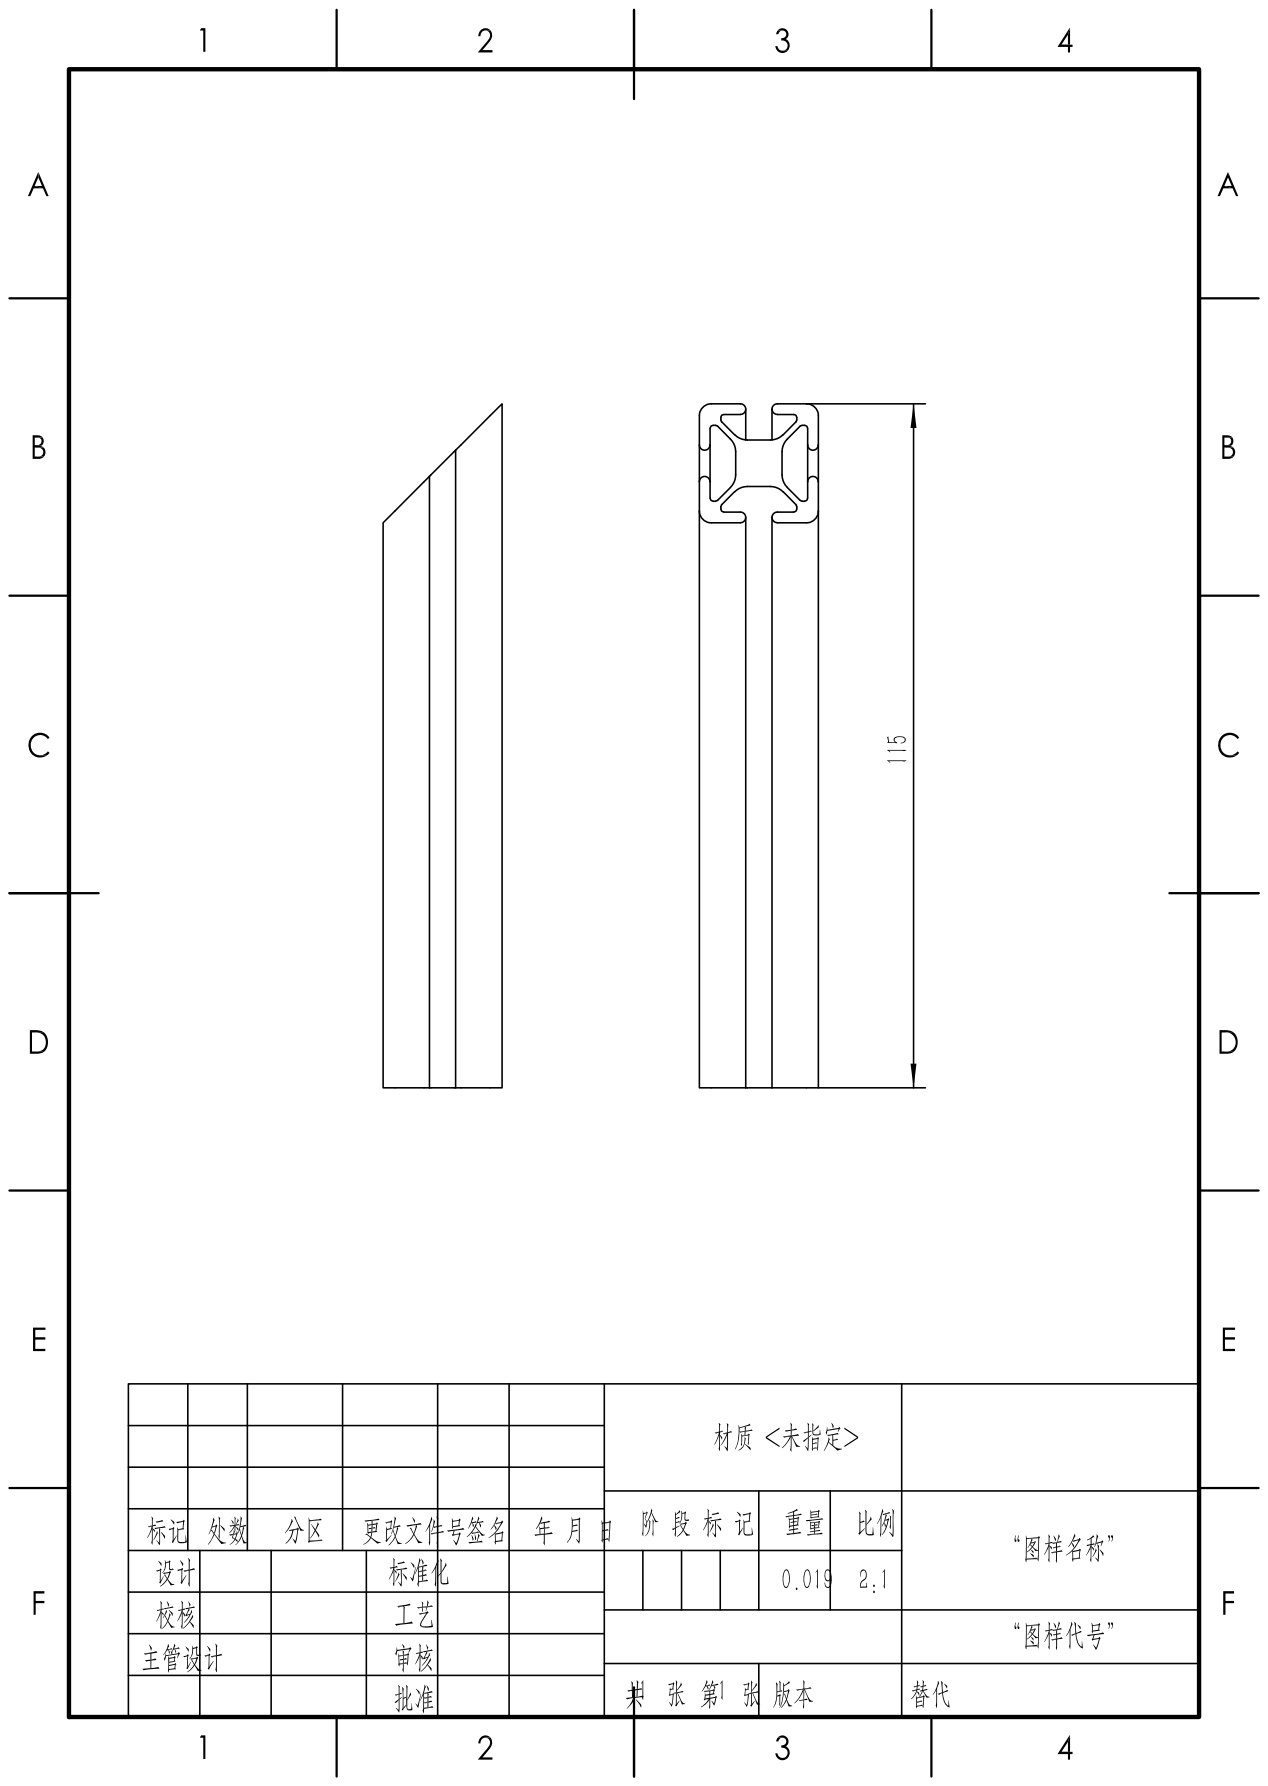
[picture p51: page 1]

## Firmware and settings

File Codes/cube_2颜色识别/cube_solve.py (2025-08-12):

import time
import serial
import kociemba
from msvcrt import getch

color_ex = {
    "U": "241335662",
    "B": "454412266",
    "L": "565163122",
    "F": "325554414",
    "D": "133426311",
    "R": "623341556",
}


class CubeSolver:
    def __init__(self, serialPort="COM5", baudRate=115200, timegap=1, msp=100, mtp=70):
        self.serialPort = serialPort
        self.baudRate = baudRate
        self.SerialUSB = serial.Serial(serialPort, baudRate, timeout=0.5)
        print("-----" * 9)
        if not self.SerialUSB.is_open:
            print("cannot open {}!".format(self.serialPort))
            quit()
        print("Successfully open {}!".format(self.serialPort))
        self.SerialUSB.write(
            (
                "[start"
                + "("
                + str(timegap)
                + ")"
                + "("
                + str(msp)
                + ")"
                + "("
                + str(mtp)
                + ")"
                + "]"
            ).encode("utf-8")
        )
        for i in range(4):
            print(self.detectString(self.SerialUSB))

    def run(self, color):
        start_time = time.time()
        print("-----" * 27)
        try:
            step = self.get_step(self.color_switch(color))

        except ValueError:
            print("魔方无解，颜色识别错误")
            return False
        else:
            print('识别完成，按下回车开始！')
            while True:
                Input = getch()
                if Input == b'\r':
                    break
            self.SerialWrite('c')
            time.sleep(1)
            self.SerialWrite(step)
            self.SerialWrite("end")
            self.time_record(start_time)
            print("-----" * 9)
            return True

    def color_switch(self, color):
        sequence = (
            color["U"] + color["R"] + color["F"] + color["D"] + color["L"] + color["B"]
        ).lower()
        U, R, F, D, L, B = sequence[4:53:9]
        dic = {U: "U", R: "R", F: "F", D: "D", L: "L", B: "B"}
        for char in dic:
            sequence = sequence.replace(char, dic[char])
        return sequence

    def get_step(self, sequence):
        SolveSteps = kociemba.solve(sequence)
        SolveSteps = SolveSteps.split(" ")
        l = len(SolveSteps)
        for i in range(l):
            if len(SolveSteps[i]) == 1:
                SolveSteps[i] = SolveSteps[i] + "1"
        print("SolveSteps:")
        print(SolveSteps)
        return self.step_switch(SolveSteps)

    def step_switch(self, Steps):
        stepNum = len(Steps)
        for k in range(stepNum):
            if Steps[k][0] == "R":
                for j in range(k + 1, stepNum):
                    if Steps[j][0] == "U":
                        Steps[j] = "R" + Steps[j][1]
                    elif Steps[j][0] == "R":
                        Steps[j] = "D" + Steps[j][1]
                    elif Steps[j][0] == "D":
                        Steps[j] = "L" + Steps[j][1]
                    elif Steps[j][0] == "L":
                        Steps[j] = "U" + Steps[j][1]
            elif Steps[k][0] == "U":
                for j in range(k + 1, stepNum):
                    if Steps[j][0] == "U":
                        Steps[j] = "D" + Steps[j][1]
                    elif Steps[j][0] == "R":
                        Steps[j] = "L" + Steps[j][1]
                    elif Steps[j][0] == "D":
                        Steps[j] = "U" + Steps[j][1]
                    elif Steps[j][0] == "L":
                        Steps[j] = "R" + Steps[j][1]
            elif Steps[k][0] == "L":
                for j in range(k + 1, stepNum):
                    if Steps[j][0] == "U":
                        Steps[j] = "L" + Steps[j][1]
                    elif Steps[j][0] == "R":
                        Steps[j] = "U" + Steps[j][1]
                    elif Steps[j][0] == "D":
                        Steps[j] = "R" + Steps[j][1]
                    elif Steps[j][0] == "L":
                        Steps[j] = "D" + Steps[j][1]
            elif Steps[k][0] == "B":
                for j in range(k + 1, stepNum):
                    if Steps[j][0] == "F":
                        Steps[j] = "B" + Steps[j][1]
                    elif Steps[j][0] == "R":
                        Steps[j] = "L" + Steps[j][1]
                    elif Steps[j][0] == "B":
                        Steps[j] = "F" + Steps[j][1]
                    elif Steps[j][0] == "L":
                        Steps[j] = "R" + Steps[j][1]
            elif Steps[k][0] in ["F", "D"]:
                None
            else:
                print("{} goes wrong, please check!".format(Steps[k][0]))
                quit()
        print("SwitchSteps:")
        print(Steps)
        return Steps

    def detectString(self, com):
        while not com.in_waiting:
            continue
        rstr = str(com.readline(), encoding="utf-8")
        if rstr[0] == "[" and rstr[-3] == "]":
            return rstr[1:-3]
        else:
            print("Please check arduino!")
            return False

    def SerialWrite(self, Steps):
        if isinstance(Steps, str):
            self.SerialUSB.write(("[" + Steps + "]").encode("utf-8"))
            if self.detectString(self.SerialUSB):
                return True
            else:
                return False
        for step in Steps:
            self.SerialUSB.write(("[" + step + "]").encode("utf-8"))
            print(step, "successfully sent!")

    def time_record(self, start_time):
        while 1:
            step = self.detectString(self.SerialUSB)
            if step == "end":
                print("还原结束，总用时:", format(time.time() - start_time, ".3f"))
                break
            print(step, "用时:", format(time.time() - start_time, ".3f"))

    def close(self):
        self.SerialUSB.write("[close]".encode("utf-8"))
        print(self.detectString(self.SerialUSB))
        self.SerialUSB.close()
        print("-----" * 9)

'''
test = cube_solve(serialPort="COM5", timegap=1, msp=100, mtp=70)
test.SerialWrite("c")
time.sleep(3)
while 1:
    if not test.run(color_ex, 1):
        print("重新识别")
    else:
        break
test.close()
'''

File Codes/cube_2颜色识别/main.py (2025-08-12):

from cube import Cube 
from msvcrt import getch
import sys
from tool import window_capture
from getopt import getopt
from pywintypes import error as WindowCaptureError

serialUSB = 'COM3'
baudRate = 115200
mode = None
timegap=1
msp=100
mtp=70

try:
	opts, arg = getopt(args=sys.argv[1:], shortopts='ihs:b:', longopts=['mode=','msp','mtp','timegap'])
except getopt.GetoptError:
	print('参数设置错误，使用:\n"python main.py -h"\n查看用法')
	sys.exit()

assert opts != [] , '请输入参数，使用:\n"python main.py -h"\n查看用法'

def init():
	with open('./models/cnn_model.txt', 'w') as file:
		file.write('./models/cnn.h5')
	with open('./models/stacking_model.txt', 'w') as file:
		file.write('./models/StackingClassifier.pkl')

for opt, arg in opts:
	if opt == '-i':
		init()
	if opt == '-h':
		helper = '''使用方法：
python main.py --mode mode [-s serialUSB -b baudRate -i]
其中，mode为运行模式，train为训练模式，run为使用模式
serialUSB为Arduino端口，默认为com5
baudRate为Arduino波特率，默认为115200
i将初始化模型使用
请务必不要最小化OBS窗口'''
		print(helper)
		sys.exit()
	if opt == '--mode':
		mode = arg
	if opt == '-s':
		serialUSB = arg
	if opt == '-b':
		baudRate = int(arg)
	if opt == '--timegap':
		timegap =int(arg)
	if opt == '--msp':
		msp = int(msp)
	if opt == '--mtp':
		mtp = int(mtp)

assert mode in ['run', 'train', 'test'] , 'mode参数有误，使用:\n"python main.py -h"\n查看用法'

try:
	window_capture()
except WindowCaptureError:
	print('请打开OBS，使用:\n"python main.py -h"\n查看用法')
	sys.exit()

if mode == 'train':
	print('放置完成后，按下回车开始训练！')
	while True:
		Input = getch()
		if Input == b'\r':
			break

	cube = Cube(train=True, test=False, serialPort=serialUSB, baudRate=baudRate, timegap=timegap, msp=msp, mtp=mtp)
	cube.run()

if mode == 'run':
	'''
	print('所有模块加载完成，按下回车开始！')
	while True:
		Input = getch()
		if Input == b'\r':
			break
	'''
	cube = Cube(train=False, test=False, serialPort=serialUSB, baudRate=baudRate, timegap=timegap, msp=msp, mtp=mtp)
	cube.run()


if mode == 'test':
	print('所有模块加载完成，按下回车开始！')
	while True:
		Input = getch()
		if Input == b'\r':
			break

	cube = Cube(train=False, test=True, serialPort=serialUSB, baudRate=baudRate, timegap=timegap, msp=msp, mtp=mtp)
	cube.run()

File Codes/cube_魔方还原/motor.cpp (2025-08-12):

#include "config.h"
#include "Arduino.h"

int timegap = 1;            //步进电机转速调节
#define startgap 100        //步进电机起始转速
#define gapa 1              //步进电机加速度
#define range 12800 * 5 / 3 //步进电机转角范围

#define leftDir 0   //leftDir
#define leftMove 1  //leftMove
#define leftEn 2    //leftEn
#define rightDir 3  //rightDir
#define rightMove 4 //rightMove
#define rightEn 5   //rightEn

void motor_Init() //步进电机初始化
{
    pinMode(leftDir, OUTPUT); //控制方向
    pinMode(rightDir, OUTPUT);
    pinMode(leftMove, OUTPUT); //控制动力
    pinMode(rightMove, OUTPUT);
    pinMode(leftEn, OUTPUT);
    pinMode(rightEn, OUTPUT);
    digitalWrite(leftEn, 0);
    digitalWrite(rightEn, 0);
    delay(500);
    digitalWrite(leftEn, 1);
    digitalWrite(rightEn, 1);
}

void motorcl(bool lr, bool dir, int ang) //控制电机旋转，lr 0为左 1为右，dir 0为逆 1为顺，ang 旋转的角度
{
    int move;
    if (lr)
    {
        digitalWrite(rightDir, dir);
        move = rightMove;
    }
    else
    {
        digitalWrite(leftDir, dir);
        move = leftMove;
    }
    int count = 0;
    for (int gap = startgap; gap > timegap; gap -= gapa)
    {
        digitalWrite(move, HIGH);
        delayMicroseconds(gap);
        digitalWrite(move, LOW);
        delayMicroseconds(gap);
        count += 1;
    }
    for (int i = count; i < (ang * range - count); i++)
    {
        digitalWrite(move, HIGH);
        delayMicroseconds(timegap);
        digitalWrite(move, LOW);
        delayMicroseconds(timegap);
    }
    for (int gap = timegap; gap < startgap; gap += gapa)
    {
        digitalWrite(move, HIGH);
        delayMicroseconds(gap);
        digitalWrite(move, LOW);
        delayMicroseconds(gap);
    }
}

void motoroc(bool oc) //控制电机使能
{
    if (oc)
    {
        digitalWrite(leftEn, HIGH);
        digitalWrite(rightEn, HIGH);
    }
    else
    {
        digitalWrite(leftEn, LOW);
        digitalWrite(rightEn, LOW);
    }
}

void motorwt(bool lr, bool dir, int ang) //控制电机微调
{
    int move;
    if (lr)
    {
        digitalWrite(rightDir, dir);
        move = rightMove;
    }
    else
    {
        digitalWrite(leftDir, dir);
        move = leftMove;
    }
    for (int c = 0; ang > c; c += 1)
    {
        digitalWrite(move, HIGH);
        delayMicroseconds(3);
        digitalWrite(move, LOW);
        delayMicroseconds(3);
    }
}
